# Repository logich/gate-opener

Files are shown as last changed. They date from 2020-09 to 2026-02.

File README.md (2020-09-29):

# gate-opener
Purpose: documenting my frankenstein driveway gate opener project with homekit, security+ RF, and solar battery backup. 

## History
Many years ago I bought a [US Automatic Sentry 300](usa-sentry_install.pdf) gate opener that served me well for over 10 years with minimal effort, but recently parts were harder to come by and I needed to replace both the operating arm and control board because of compoment failures.

This meant that I had a large weatherproof box, a solar panel, and solar battery charger that were useful.

## Control Board and Arm
Locally I was able to buy a [GTO Mighty Mule opener](https://www.mightymule.com/wp-content/uploads/MM600-Manual-07-06-2010.pdf)

the control board is smaller, and when I removed it from the box I mounted it to one of the standoff posts and braced it on the solar charge controller.

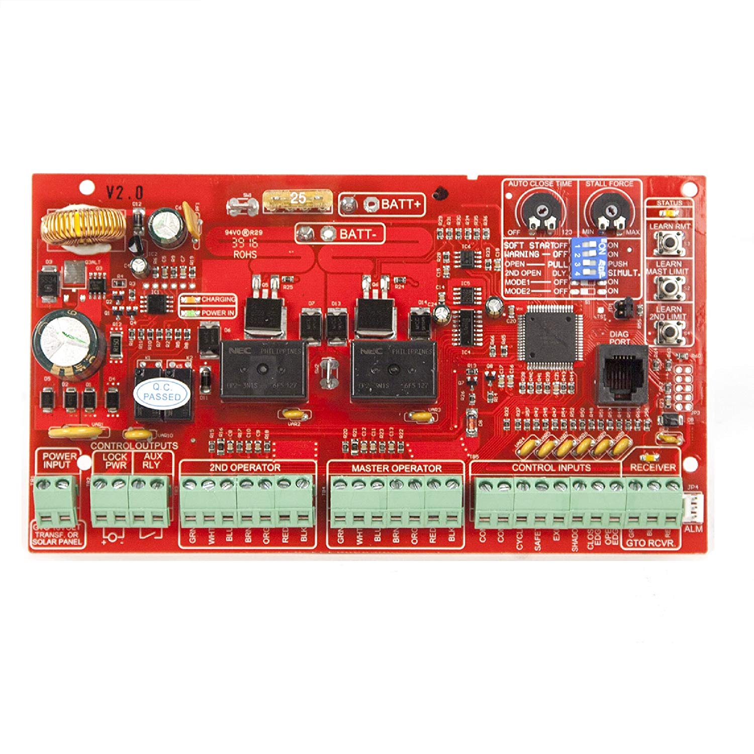
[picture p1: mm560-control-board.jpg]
control board image


I had to modify the existing wiring harness to easily attach the board to the existing battery. This made things pretty ugly since I used a bunch of crimp splices. but it gave me a fuse to prevent future issues with power draw frying the board the way it did on the old controller.

This setup charges the battery with the 18v DC from the GTO board and with the solar panel.

I initially wired up with US Automatic LCR reciever to this board so I could use GTO and US Automatic controllers. 

## Adding HomeKit Control
Since I wanted to experiment with having a homekit controlled gate, I added a Sonoff SV that has been modified to be a NO momentary switch and flashed with a homekit firmware. I soldered a small dupont wire pigtail for 12v power to the GTO board. This is wired to the COM and CYCLE inputs. I removed the LCR reciever when I added this one. More can be found in this gist: [Turning a Sonoff SV into a Home Kit Accessory to Operate a GTO Mighty Mule gate opener](https://gist.github.com/logich/4f3eeb53146414549744a3ba44705c08)

## Adding Security+ Control
After 4 years the GTO reciever began to fail and would only open at very short range. It was about as expensive to replace this with the same model as to buy a better quality liftmaster controller. I purchased a [850LM](https://smile.amazon.com/gp/product/B0071EYS9M/ref=ppx_yo_dt_b_search_asin_title?ie=UTF8&psc=1) that can be powered off 12v. 

This was wired direct to the wiring harness after the fuse for 12v power and the first switch control was wired to COM and CYCLE inputs.

The recieve distance on this controller is far longer than the GTO module and the frequencies it uses are better handled by the homelink controllers in my vehicles.

This was especially evident with my GMC truck and Tesla. The range is about the same on the version in my Honda.

## Manual Switch
I put in a small monetary switch on the bottom of the waterproof box as a backup access mode in case my transmitters were not functional. This is also wired to COM and CYCLE inputs.

## Current State
Here is an image as of September 2020 with all the messy wires:
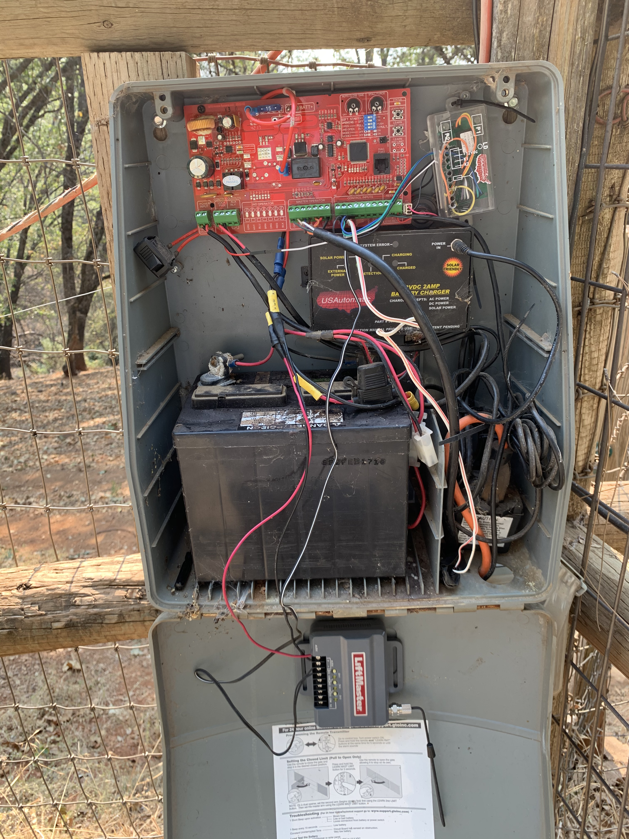
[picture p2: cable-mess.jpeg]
cable mess in box


## Future Plans
* replace remote switch with push button for visitors (like a doorbell)
* add [12v security light](https://smile.amazon.com/gp/product/B07MV2YL9J/ref=ppx_yo_dt_b_asin_title_o00_s00?ie=UTF8&psc=1)
* replace poorly wired 110v power line with low volatge direct bury line from house
* attach open and close limit sensors (waterproof reed switch) to sonoff for better homekit measurement
* put eufy camera inside enclosure
* measure the overall current draw and backup battery life
* replace lucite LCR box with project box for sonoff
* setup terminal block bus for COM and CYCLE

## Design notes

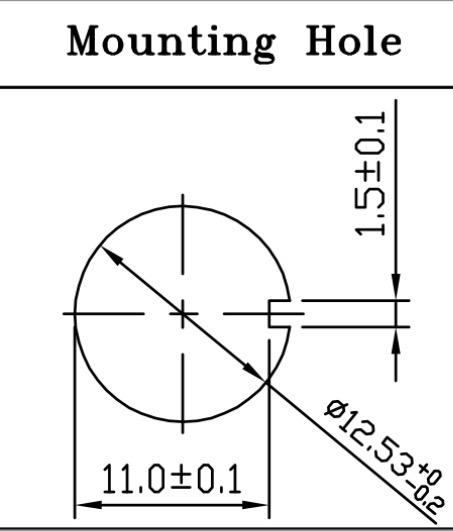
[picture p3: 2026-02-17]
mounting-hole.jpg

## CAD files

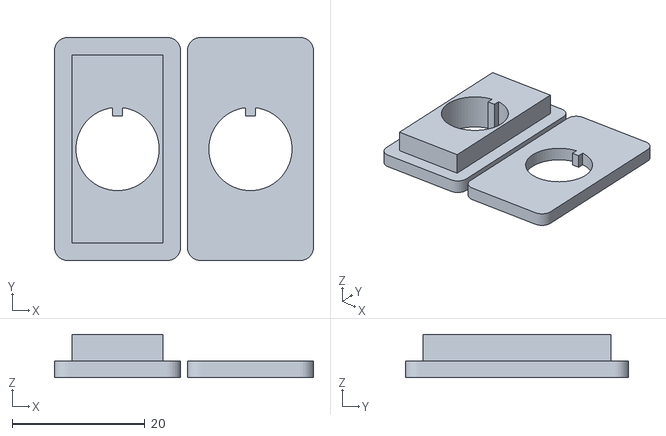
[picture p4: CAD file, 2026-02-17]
switch-adapter.stl
39.0 x 33.6 x 6.50

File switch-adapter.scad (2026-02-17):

// ============================================================
// Rocker-to-Toggle Switch Adapter Plate
// ============================================================
// Fills a Gardner Bender GSW-41 rocker switch panel cutout and
// provides a mounting hole for a standard toggle switch.
//
// Rocker switch cutout (GSW-41): 0.550" x 1.125" (14mm x 28.58mm)
//
// HOW TO USE:
//   1. Measure your toggle switch bushing/thread outer diameter
//   2. Set `toggle_hole_dia` to that value (see notes below)
//   3. Measure your enclosure panel thickness; set `panel_thickness`
//   4. Print with PLA/PETG, 3+ perimeters, 30%+ infill, no supports
//   5. Press adapter into the cutout from the outside; the flange
//      sits flush on the panel surface. Secure with toggle switch
//      nut from the inside.
//
// PRINT ORIENTATION: flange face DOWN on the build plate.
// ============================================================

// ---------- KEY PARAMETERS (adjust these) ----------

// Outer diameter of your toggle switch bushing/threads (mm).
// Gardner Bender GSW-series toggle switches (GSW-18, GSW-124, etc.)
// require a 1/2" (12.7 mm) panel hole.
//
// Common values:
//   6.0  = mini toggle (small/inexpensive units)
//   6.35 = 1/4" standard toggle
//  12.0  = 15/32" medium toggle
//  12.7  = 1/2" full-size toggle (Gardner Bender GSW series default)
//
// ⚠ IMPORTANT — narrow-wall warning:
// The rocker cutout is only 14 mm wide. With a 12.7 mm hole the
// wall on each side is ~0.5 mm. This is thin but acceptable because
// the toggle's locking nut (tightened from inside the box) provides
// the retention force. Use 3+ perimeters and 100% infill, or print
// in PETG for extra toughness.
toggle_hole_dia = 12.7;

// Thickness of the panel the rocker switch was mounted in (mm).
// Measure with calipers. A typical ABS/polycarbonate project box
// wall is 2–4mm. Use 3.0 as a starting estimate.
panel_thickness = 3.0;

// ---------- ROCKER CUTOUT DIMENSIONS (GSW-41, do not change) ----------
rocker_w = 14.0;   // 0.550" = 13.97 mm
rocker_h = 28.6;   // 1.125" = 28.58 mm

// ---------- FIT & GEOMETRY PARAMETERS ----------

// Reduce plug body by this amount (each side) for press-fit clearance.
// 0.15 mm per side (0.3 mm total) works well on most FDM printers.
// Increase to 0.2 if it's too tight after printing.
fit_clearance = 0.15;

// How far the flange lip overhangs the cutout on each side (mm).
flange_overhang = 2.5;

// Thickness of the flange (the visible face plate).
flange_thickness = 2.5;

// Corner radius on the flange (cosmetic).
flange_corner_r  = 2.0;

// Extra plug depth beyond the panel so the fit has some grip
// before the toggle nut is tightened. 1 mm is plenty.
plug_extra_depth = 1.0;

// ---------- DERIVED DIMENSIONS (do not edit) ----------
plug_w     = rocker_w - fit_clearance * 2;
plug_h_dim = rocker_h - fit_clearance * 2;
plug_depth = panel_thickness + plug_extra_depth;

flange_w = rocker_w + flange_overhang * 2;
flange_h = rocker_h + flange_overhang * 2;

total_height = flange_thickness + plug_depth;

// ============================================================
// MODEL
// Print orientation: flange face on build plate (Z=0).
// Z increases upward through the plug.
// ============================================================
difference() {
    union() {
        // Flange — rests on panel exterior, centered at (0,0)
        rounded_rect(flange_w, flange_h, flange_thickness, flange_corner_r);

        // Plug body — inserts into the rocker cutout
        // Cube bottom starts at z=flange_thickness; center=true needs
        // the translate at the cube's center: flange_thickness + plug_depth/2
        translate([0, 0, flange_thickness + plug_depth / 2])
            cube([plug_w, plug_h_dim, plug_depth], center = true);
    }

    // Toggle switch mounting hole — centered, runs full height + margin
    translate([0, 0, total_height / 2])
        cylinder(h = total_height + 2, d = toggle_hole_dia,
                 center = true, $fn = 64);
}

// ============================================================
// Helper: rounded-corner rectangle, centered at origin in X/Y,
// bottom face at Z=0, top face at Z=depth.
// ============================================================
module rounded_rect(w, h, depth, r) {
    hull() {
        for (x = [-w/2 + r, w/2 - r])
            for (y = [-h/2 + r, h/2 - r])
                translate([x, y, 0])
                    cylinder(h = depth, r = r, $fn = 32);
    }
}

// ============================================================
// Mounting Hole Cutout — panel cutout for a toggle switch with
// a cylindrical body, two parallel flats, and an anti-rotation
// notch on the right side.
//
// Datasheet geometry:
//   Circle diameter  : 12.53 +0.0/-0.2 mm  → r = 6.265 mm
//   Width across flats: 11.0 ± 0.1 mm      → flats at x = ±5.5 mm
//   Notch offset     : 1.5 ± 0.1 mm from centerline (y = +1.5 mm)
//
// Usage: use mounting_hole_cutout() inside a difference() to cut
// through a panel.  The bottom face sits at Z=0; top at Z=depth.
// ============================================================
module mounting_hole_cutout(depth = 3) {
    r      = 12.53 / 2;  // 6.265 mm — circle radius
    flat_x = 11.0  / 2;  // 5.5 mm  — half of width-across-flats

    union() {
        // Main body: full cylinder with the two vertical flats removed
        difference() {
            cylinder(h = depth, d = 12.53, $fn = 64);

            // Left flat  — remove everything beyond x = -5.5 mm
            translate([-(r + 1), -(r + 1), -0.5])
                cube([r + 1 - flat_x, 2 * (r + 1), depth + 1]);

            // Right flat — remove everything beyond x = +5.5 mm
            translate([flat_x, -(r + 1), -0.5])
                cube([r + 1 - flat_x, 2 * (r + 1), depth + 1]);
        }

        // Anti-rotation notch on the right side.
        // Rectangle: 1.5 mm wide (x), 1.5 mm tall (y),
        // centered at y = +1.5 mm above the horizontal centerline.
        translate([flat_x, 1.5 - 0.75, 0])
            cube([1.5, 1.5, depth]);
    }
}

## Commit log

2026-02-17 Add parametric OpenSCAD adapter for rocker-to-toggle switch swap
    Fills Gardner Bender GSW-41 rocker cutout (0.550" x 1.125" / 14x28.6mm)
    with a press-fit adapter plate that accepts a Gardner Bender GSW-series
    (or other standard 1/2" bushing) toggle switch.
    Key parameters:
    - toggle_hole_dia: defaults to 12.7mm (1/2") for Gardner Bender GSW series
    - panel_thickness: set to match your enclosure wall depth
    - fit_clearance: 0.15mm per side for FDM press-fit
    Print flange-face-down, 3+ perimeters, 100% infill recommended due to
    narrow (~0.5mm) walls adjacent to the mounting hole.
    https://claude.ai/code/session_014ugcF6HELgnuhF6hxYBuj7
    [switch-adapter.scad]
2026-02-17 Add mounting_hole_cutout module for panel switch cutout
    Adds a new module implementing the datasheet geometry for a panel
    cutout with:
    - Circular body: 12.53mm diameter ($fn=64)
    - Two vertical flats via cube() subtraction at x = ±5.5mm
    (11.0mm width across flats)
    - Anti-rotation notch (1.5×1.5mm) on the right side, centered
    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
    [switch-adapter.scad]
2026-02-17 updates to scad file to ensure keyway and create sandwiched flanges to hold adapter to box
    [switch-adapter.stl]
